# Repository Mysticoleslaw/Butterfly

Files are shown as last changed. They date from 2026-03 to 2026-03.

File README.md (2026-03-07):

# RC Butterfly Flight Controller

A flight controller for an RC butterfly that uses an ESP32 to control two wing servos based on FrSky S.bus input from a 4XR receiver.

## Features

- **Throttle Control**: Controls the flap rate (speed) of the wings
- **Aileron Control**: Controls turning by reducing flap amplitude on one wing
- **Flap Enable Switch**: On/off control for flapping
- **Opposite Wing Motion**: Wings flap in opposite directions for realistic butterfly flight
- **Failsafe Protection**: Automatically returns to neutral position if signal is lost
- **No Inverter Needed**: ESP32 handles inverted S.bus signals in hardware

## Hardware Requirements

### Required Components
- **Waveshare ESP32-C3 Mini Development Board**
- **FrSky 4XR 3/16 channel receiver** with S.bus output
- **Two standard servos** (9g or similar) for wing control
- Power supply for servos (if not powered through ESP32-C3)

### Optional Components
- USB cable for programming and debugging
- Breadboard and jumper wires for prototyping

## Wiring

```
FrSky 4XR Receiver
    |
    | S.bus OUT (direct connection, no inverter!)
    |
ESP32-C3 Mini GPIO 4 (UART1 RX)
    |
    | Control signals
    |
Servo 1 (Left Wing)  -> GPIO 5
Servo 2 (Right Wing) -> GPIO 6
```

### Pin Connections (Waveshare ESP32-C3 Mini)

| Component | ESP32-C3 Pin | Notes |
|---|---|---|
| S.bus Signal | GPIO 4 | UART1 RX |
| Left Wing Servo | GPIO 5 | PWM pin |
| Right Wing Servo | GPIO 6 | PWM pin |

**Note**: Pins are configurable. You can change `SBUS_RX_PIN`, `SERVO_LEFT_PIN`, and `SERVO_RIGHT_PIN` in the code to use different GPIO pins if needed.

## Software Setup

### 1. Install Required Libraries

1. **FrSky S.bus Library**: 
   - Copy the `frsky-sbus-main/src` folder to your Arduino `libraries` folder
   - Rename it to `FrskySbus`
   - Location: `~/Documents/Arduino/libraries/FrskySbus/`

2. **ESP32Servo Library**:
   - Install via Arduino Library Manager: Sketch → Include Library → Manage Libraries → Search "ESP32Servo"
   - Or via command line: `arduino-cli lib install "ESP32Servo"`

### 2. Install ESP32 Board Support

1. In Arduino IDE: File → Preferences → Additional Board Manager URLs
2. Add: `https://raw.githubusercontent.com/espressif/arduino-esp32/gh-pages/package_esp32_index.json`
3. Tools → Board → Boards Manager → Search "ESP32" → Install "esp32 by Espressif Systems"

### 3. Upload the Code

1. Open `ButterflyFlightController_ESP32.ino` in Arduino IDE
2. Select your board: Tools → Board → ESP32 Arduino → ESP32C3 Dev Module
3. Select the correct port: Tools → Port → [Your ESP32-C3 port]
4. Upload the sketch

## How It Works

### Flap Rate Control (Throttle)
- **Low Throttle**: Slow, gentle flapping (500ms period)
- **High Throttle**: Fast, aggressive flapping (50ms period)
- The throttle stick position directly controls the speed of wing movement

### Turning Control (Aileron)
- **Neutral**: Both wings flap with full amplitude (45° range: 45° to 135°)
- **Left Stick**: Left wing amplitude reduces (e.g., 68° to 112°), right wing keeps full amplitude → turns left
- **Right Stick**: Right wing amplitude reduces, left wing keeps full amplitude → turns right
- The differential amplitude creates asymmetric lift for turning

### Flap Enable (Channel 3)
- **ON** (above center): Flapping enabled, responds to throttle and aileron
- **OFF** (below center): Flapping disabled, wings return to center (90°), ignores throttle and aileron

### Wing Motion
- Wings flap in **opposite directions** (left up = right down, and vice versa)
- This creates realistic butterfly flapping motion
- Both wings always flap around center (90°), but with different amplitudes when turning

### Failsafe Protection
- If no S.bus signal is received for 500ms, failsafe activates
- Wings automatically return to center position
- Flapping stops
- Normal operation resumes when signal is restored

## Calibration and Tuning

### Adjusting Flap Speed Range
Modify these constants in the code:
```cpp
const unsigned long MIN_FLAP_PERIOD = 50;   // Fastest flapping (ms)
const unsigned long MAX_FLAP_PERIOD = 500;  // Slowest flapping (ms)
```

### Adjusting Flap Amplitude
Change the wing movement range:
```cpp
const int FLAP_AMPLITUDE_FULL = 45;  // Full amplitude when straight (degrees)
const int FLAP_AMPLITUDE_MIN = 22;  // Minimum amplitude when turning (degrees)
```

### Adjusting Turn Sensitivity
Modify the maximum turn reduction:
```cpp
const int MAX_TURN_REDUCTION = 23;  // Maximum amplitude reduction for turning (degrees)
```

### Adjusting Servo Range
If your servos need different limits:
```cpp
const int SERVO_MIN = 45;   // Minimum servo position (degrees)
const int SERVO_MAX = 135;  // Maximum servo position (degrees)
const int SERVO_CENTER = 90; // Center position (degrees)
```

### Channel Mapping
If your transmitter channels are different, modify:
```cpp
#define THROTTLE_CHANNEL 0  // Change to your throttle channel (0-15)
#define AILERON_CHANNEL 1   // Change to your aileron channel (0-15)
#define FLAP_ENABLE_CHANNEL 2  // Change to your enable channel (0-15)
```

## Transmitter Setup

Configure your transmitter with:
- **Channel 1**: Throttle stick (controls flap rate)
- **Channel 2**: Aileron stick (controls turning)
- **Channel 3**: 2-position or 3-position switch (enables/disables flapping)

## Troubleshooting

### No Wing Movement
1. Check that servos are connected to GPIO 18 and 19
2. Verify servo power supply (servos may need external power)
3. Check Serial Monitor for error messages
4. Verify S.bus signal is being received (check debug output)

### Erratic Movement
1. Ensure S.bus signal is reaching the ESP32
2. Check GPIO 16 connection
3. Verify transmitter is bound to receiver
4. Check that channel mapping matches your transmitter

### Failsafe Always Active
1. Verify S.bus signal is reaching GPIO 16
2. Check receiver is powered and bound
3. Ensure S.bus is enabled on receiver (some receivers need configuration)
4. Check Serial Monitor for connection status

### Wings Not Centered
1. Adjust `SERVO_CENTER` value if needed
2. Physically adjust servo horns if needed
3. Use transmitter trim if available

## Debugging

The code includes Serial output for debugging. Open Serial Monitor at 115200 baud to see:
- Throttle, aileron, and flap enable channel values
- Current flap period
- Wing amplitudes for each side
- Failsafe status

To disable debug output for production, comment out or remove the Serial.print statements in the loop.

## Why ESP32-C3 Mini?

The Waveshare ESP32-C3 Mini is ideal for this project because:
- **Hardware UART**: Dedicated hardware serial (not software emulation)
- **Native Inverted Signal Support**: Handles inverted S.bus signals in hardware - no inverter circuit needed!
- **Reliable at 100000 Baud**: Handles S.bus speed easily without jitter
- **Better Performance**: Smooth, responsive control
- **Compact Size**: Small form factor perfect for RC applications
- **Low Power**: Efficient operation for battery-powered projects

## Safety Notes

- Always test with the butterfly secured before free flight
- Start with low throttle settings to verify control
- Ensure failsafe is working before flight
- Check all connections before powering on
- Use appropriate power supply for servos (may need external supply)
- Verify all controls respond correctly before first flight

## License

This project uses the FrSky S.bus library which is based on work by Brian R Taylor and maintained by COPPERPUNK.

## Credits

- FrSky S.bus Library: [COPPERPUNK](https://github.com/copperpunk-arduino/frsky-sbus)
- Original SBUS.h library: [Brian R Taylor](https://github.com/bolderflight/SBUS)
- ESP32Servo Library: [Kevin Harrington, John K. Bennett](https://github.com/madhephaestus/ESP32Servo)

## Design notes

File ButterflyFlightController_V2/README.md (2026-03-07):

# Butterfly Flight Controller V2

Flight controller for an RC ornithopter (mechanical butterfly) running on an ESP32-C3 Mini with a FrSky RXS-R receiver.

Based on the [Ctorque Mech-Butterfly](https://github.com/) MicroPython code, rewritten in Arduino C++ with FrSky F.Port support and additional features.

## Features

- **Sinusoidal flap motion** — Smooth cosine-wave wing movement (40 steps/cycle), replacing the original binary snap flap. Produces natural, efficient wing motion.
- **Variable amplitude** — Adjust wing sweep angle in flight (20-70 degrees) via a stick or knob.
- **Pitch control** — Shift both wing centers for climb/dive bias.
- **Differential turning** — Aileron input makes one wing flap more than the other for yaw control.
- **Per-wing trim** — Independent trim correction for left and right wings via aux channels.
- **Battery monitoring** — ADC-based voltage reading with low-pass filter. Displays on serial and sends telemetry to transmitter.
- **F.Port telemetry** — Battery voltage (VFAS) and percentage (Fuel) code included but currently disabled (F.Port set to RX-only due to GPIO 7 half-duplex conflict on ESP32-C3).
- **Non-blocking** — F.Port is read every loop iteration; wing motion never blocks communication.
- **WS2812 wing LEDs** — Addressable LED effects synced to flight state: rainbow wave during flapping, amber breathing when idle, red flash on failsafe, orange pulse on low battery.
- **Failsafe** — Wings center and stop flapping if F.Port signal is lost for 500ms.

## Hardware

| Component | Details |
|---|---|
| MCU | ESP32-C3 Mini Development Board (3.3V logic) |
| Receiver | FrSky RXS-R (uninverted S.Port / F.Port on P pad) |
| Servos | 2x micro servos for wing control |
| Battery | 2S LiPo (7.4V nominal) |
| BEC | 5V BEC from 2S battery to power the ESP32-C3 via VIN pin |
| Voltage divider | Resistor divider on battery line for ADC monitoring |
| LEDs | WS2812 / NeoPixel strip (mounted on wings) |

## Wiring

```
FrSky RXS-R P pad ──── GPIO 7   (F.Port, RX only)
Left wing servo ─────── GPIO 4
Right wing servo ────── GPIO 5
Battery voltage divider  GPIO 0   (ADC input)
WS2812 LED data ──────── GPIO 3   (NeoPixel strip)
5V BEC output ────────── VIN      (ESP32-C3 power)
GND ──────────────────── GND
```

### Battery Voltage Divider

The ESP32-C3 ADC can only read up to ~2.5V (with 11dB attenuation). A resistor divider scales the battery voltage down to a safe range.

```
VBAT ──[ R1 30k ]──┬──[ R2 10k ]── GND
                   └── GPIO 0
```

With R1=30k and R2=10k, the divider ratio is 4:1.

- 2S full (8.4V) / 4 = 2.1V (safe for ADC)
- 2S empty (6.6V) / 4 = 1.65V

Set `VDIV_RATIO` in the code to match your actual resistor values:

```
VDIV_RATIO = (R1 + R2) / R2
```

**Important:** Do NOT connect the battery directly to any GPIO pin. The ESP32-C3 is a 3.3V chip — voltages above 3.3V on any GPIO will damage it.

## Channel Mapping

Configure these on your FrSky transmitter (OpenTX / EdgeTX):

| Channel | Input | Function | Range |
|---|---|---|---|
| Ch 0 | Throttle | Flap speed | Slow ↔ Fast (8-16ms/step) |
| Ch 1 | Aileron | Turning (differential) | Left ↔ Right (±20 deg) |
| Ch 2 | Elevator | Pitch offset | Dive ↔ Climb (±20 deg) |
| Ch 3 | Rudder | Flap amplitude | Small ↔ Large (20-70 deg) |
| Ch 4 | Aux switch | Flap enable/disable | Below center=off, above=on |
| Ch 5 | Aux knob/slider | Left wing trim | ±20 deg |
| Ch 6 | Aux knob/slider | Right wing trim | ±20 deg |
| Ch 7 | Aux switch | LED on/off | Below center=off, above=on |
| Ch 8 | 3-pos switch | LED mode | Low=solid, Mid=rainbow, High=flap-sync |
| Ch 9 | Aux pot/slider | LED brightness | 0-100% |
| Ch 10 | Aux pot/slider | LED color hue | Full color wheel |

## Telemetry

The controller sends battery data back through F.Port. These values appear automatically on your transmitter once discovered:

| Sensor | Value | Description |
|---|---|---|
| VFAS | Voltage | Battery voltage (e.g. 7.85V) |
| Fuel | Percentage | Battery level (0-100%) |

You can set up voice alerts on the transmitter for low battery warnings.

## LED Effects

WS2812 LEDs on GPIO 3, fully controlled from the transmitter via Ch 7-10.

**Ch 7** turns LEDs on or off. **Ch 9** controls brightness. **Ch 10** selects the color hue (used by solid and flap-sync modes).

**Ch 8** selects the mode with a 3-position switch:

| Switch position | Mode | Description |
|---|---|---|
| Low | Solid | All LEDs set to the color selected by the hue pot (Ch 10) |
| Center | Rainbow | Classic auto-cycling rainbow spread across the strip |
| High | Flap-sync | Two complementary colors alternate across the strip, swapping brightness with each wing stroke |

### Flap-sync mode

The color pot (Ch 10) picks a base hue. The complementary color (180 degrees opposite on the color wheel) is calculated automatically. Even-numbered LEDs show color A, odd-numbered show color B. As the wings flap, the two colors swap dominance — at one wing extreme color A is bright and B is dim, at the other extreme they swap. This creates a shimmering, pulsing dual-color effect synced to wing motion.

### Wiring

Power the LED strip from the **5V BEC**, not from the ESP32-C3's 3.3V pin. Connect the data line to GPIO 3 (3.3V logic is fine for WS2812 data at short wire distances).

## Tuning

All parameters are defined as constants at the top of the `.ino` file:

| Constant | Default | Description |
|---|---|---|
| `DELAY_MIN_MS` | 8 | Fastest step delay (ms) — full throttle |
| `DELAY_MAX_MS` | 16 | Slowest step delay (ms) — zero throttle |
| `AMP_MIN` | 20.0 | Minimum amplitude (degrees) |
| `AMP_MAX` | 70.0 | Maximum amplitude (degrees) |
| `DIFF_MAX` | 20.0 | Maximum turning differential (degrees) |
| `PITCH_MAX` | 20.0 | Maximum pitch offset (degrees) |
| `TRIM_MAX` | 20.0 | Maximum per-wing trim (degrees) |
| `FLAP_STEPS` | 40 | Steps per full flap cycle (smoothness) |
| `VDIV_RATIO` | 4.0 | Battery voltage divider ratio |
| `BAT_VOLT_MIN` | 6.6 | 2S LiPo empty voltage |
| `BAT_VOLT_MAX` | 8.4 | 2S LiPo full voltage |
| `BAT_WARN_VOLTAGE` | 7.0 | Low battery warning threshold |
| `BAT_FILTER_ALPHA` | 0.98 | ADC smoothing (higher = smoother) |
| `LED_COUNT` | 10 | Number of WS2812 LEDs on the strip |
| `LED_UPDATE_INTERVAL_MS` | 25 | LED refresh rate (~40fps) |
| `RAINBOW_SPEED` | 300.0 | Rainbow mode rotation speed |

## Dependencies

- [ESP32Servo](https://github.com/madhephaestus/ESP32Servo) — Install via Arduino Library Manager
- [Adafruit NeoPixel](https://github.com/adafruit/Adafruit_NeoPixel) — Install via Arduino Library Manager

## Flashing

1. Open `ButterflyFlightController_V2.ino` in Arduino IDE
2. Select board: **ESP32C3 Dev Module**
3. Set **USB CDC On Boot: Enabled** (required for serial monitor over USB)
4. Install libraries: **ESP32Servo** and **Adafruit NeoPixel**
5. Connect the ESP32-C3 via USB
6. Upload

Or via `arduino-cli`:

```bash
arduino-cli compile --fqbn esp32:esp32:esp32c3:CDCOnBoot=cdc ButterflyFlightController_V2
arduino-cli upload --fqbn esp32:esp32:esp32c3:CDCOnBoot=cdc --port /dev/cu.usbmodem1101 ButterflyFlightController_V2
```

## Known Issues

- **Servo amplitude drops at high flap speeds** — The sinusoidal wave commands positions faster than budget analog servos (e.g. ES08AII at ~0.10s/60°) can physically reach. At max throttle (320ms/cycle), servos can't complete the full sweep before the wave reverses. Fix: use faster digital servos (~0.05-0.06s/60°) like the KST X08 Plus, or increase `DELAY_MIN_MS` to cap speed to what your servos can handle.
- **Telemetry disabled** — Half-duplex F.Port on GPIO 7 caused signal loss due to the open-drain configuration interfering with RX. Telemetry code remains in the sketch but the UART is set to RX-only. May work on a different GPIO or with a separate TX pin.

## Changes from V1

| Feature | V1 | V2 |
|---|----|----|
| Flap motion | Binary snap (2 positions) | Sinusoidal cosine wave (40 steps) |
| Amplitude | Fixed 45 deg | Variable 20-70 deg (Ch 3) |
| Pitch control | None | ±20 deg (Ch 2) |
| Wing trims | None | ±20 deg per wing (Ch 5-6) |
| Battery monitoring | None | ADC with low-pass filter |
| Telemetry | None | VFAS + Fuel via F.Port |
| F.Port direction | RX only | RX only (half-duplex telemetry code present but disabled) |
| Flap speed control | Period 50-500ms | Step delay 8-16ms (smoother) |
| Wing LEDs | None | WS2812 with 3 modes, RC-controlled brightness/color/on-off |

## Credits

- Original Ctorque Mech-Butterfly MicroPython code
- Wing motion algorithm ported from `Kang_Flyer_Ornithopter.py`
- Battery monitoring approach from `Kang_Battery.py`

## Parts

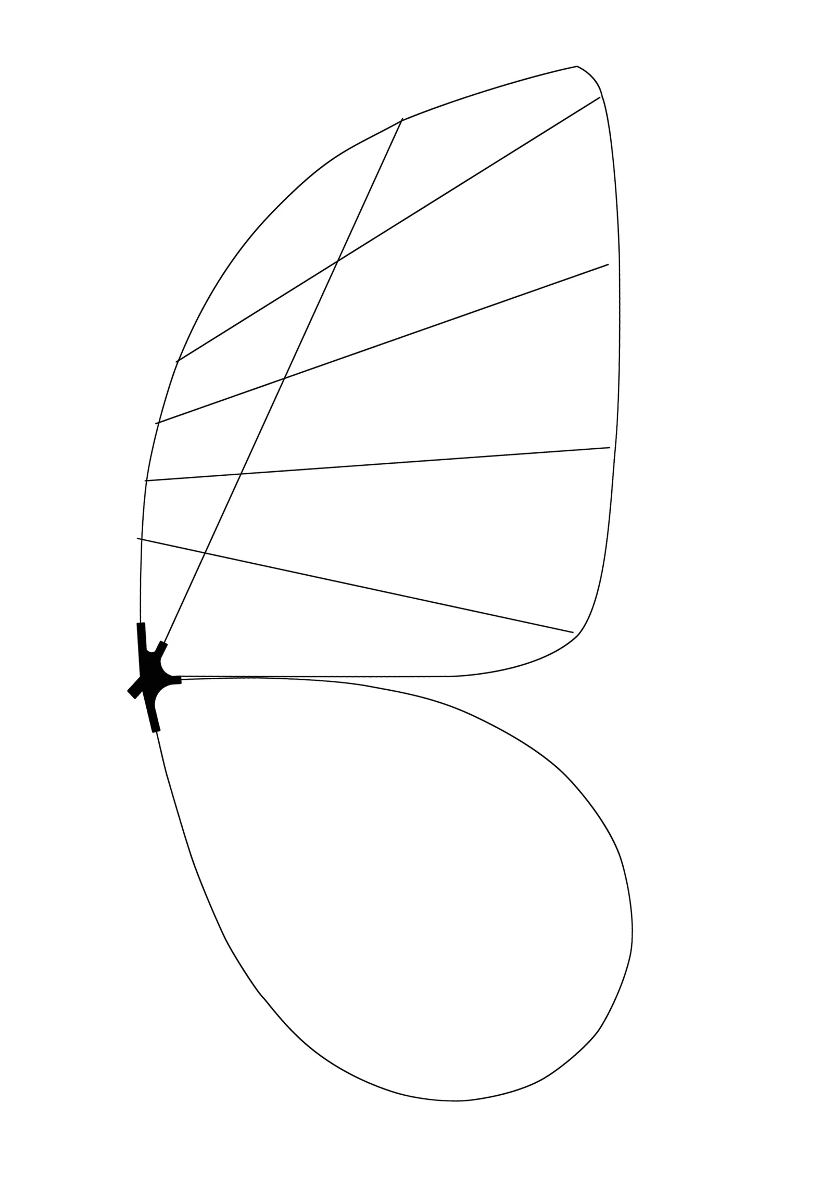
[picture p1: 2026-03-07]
Ctorque parts/a2-2-scaled.webp

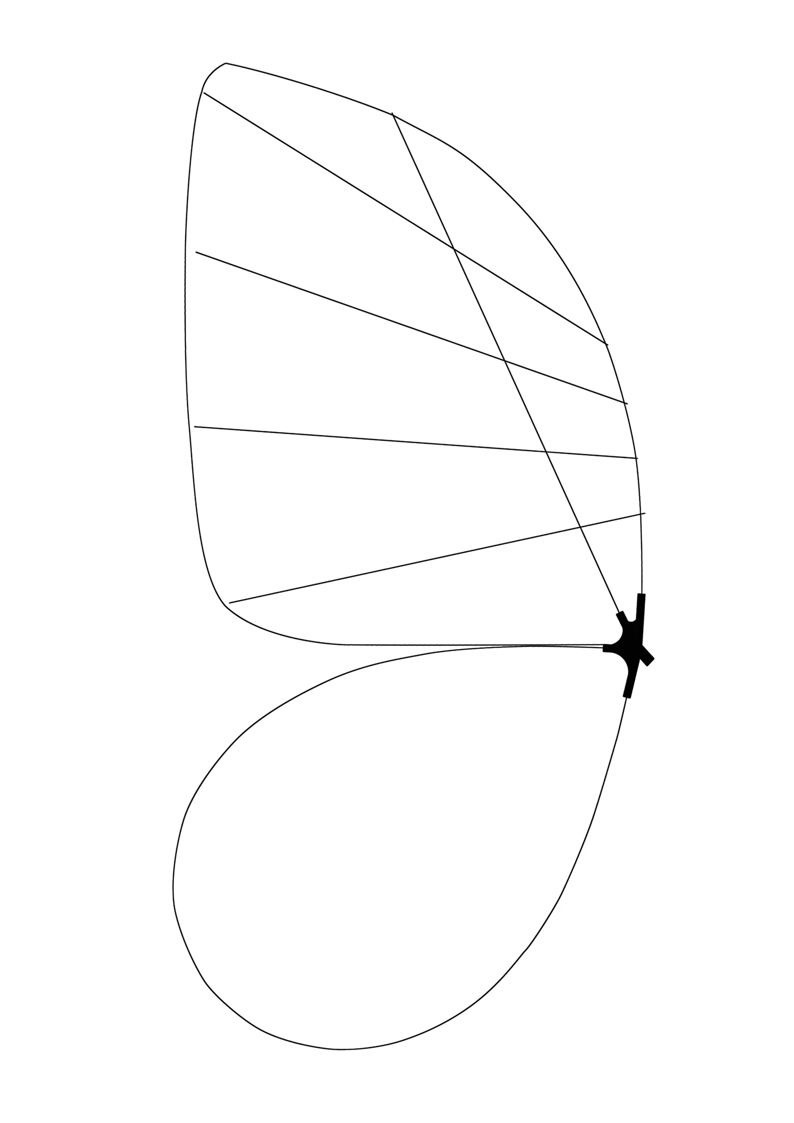
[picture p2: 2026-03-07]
Ctorque parts/A2-1-scaled.webp

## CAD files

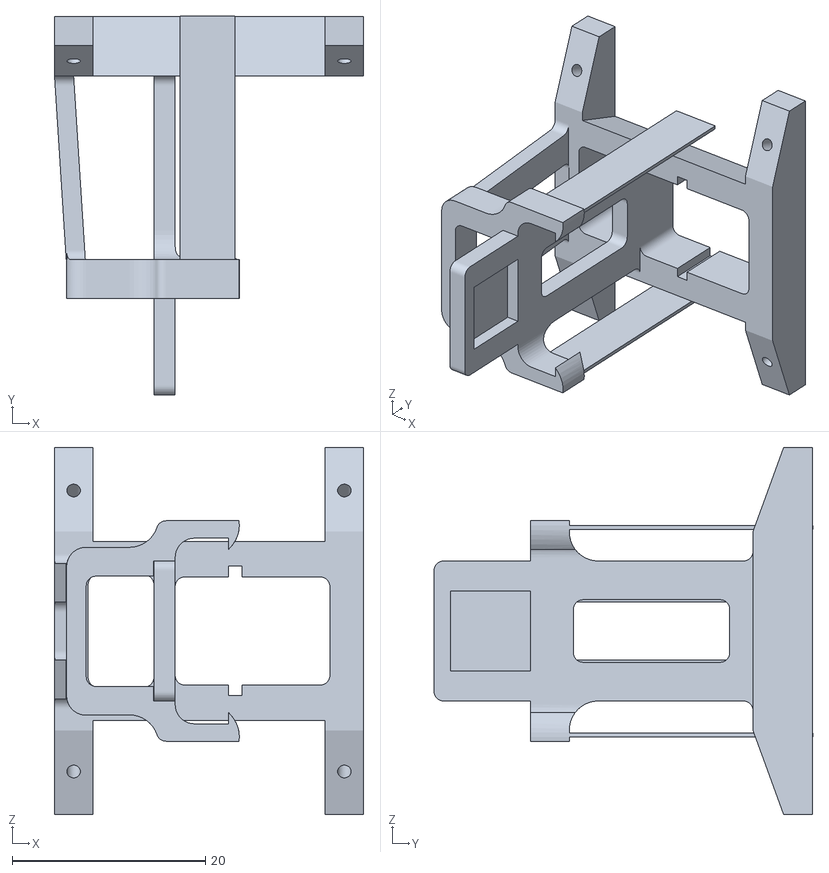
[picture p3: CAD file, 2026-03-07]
Ctorque parts/bionic butterfly mount 20260113/FC Mount V5.STL
32.0 x 39.2 x 38.0

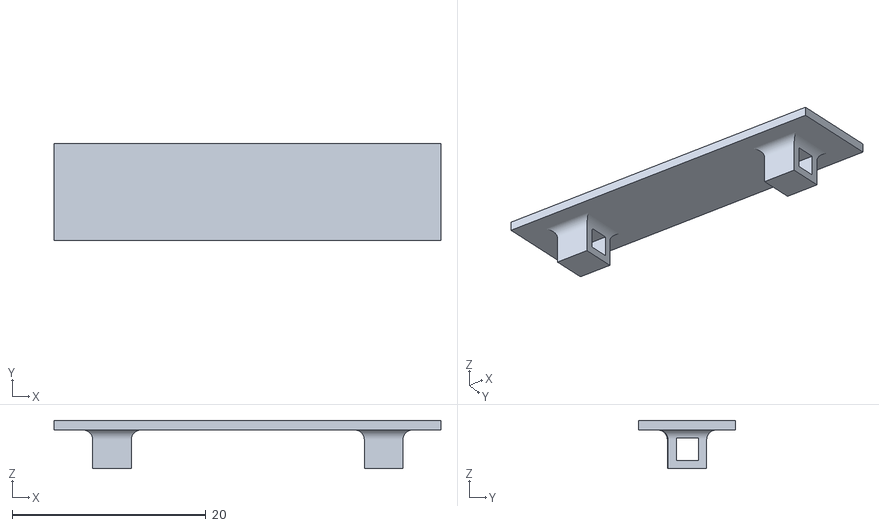
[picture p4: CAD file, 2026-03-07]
Ctorque parts/Mech-Butterfly-main/5-3D-Printed-Parts/Battery-Mount/Flight-Controller-Battery-Mount.STL
40.0 x 10.0 x 5.00

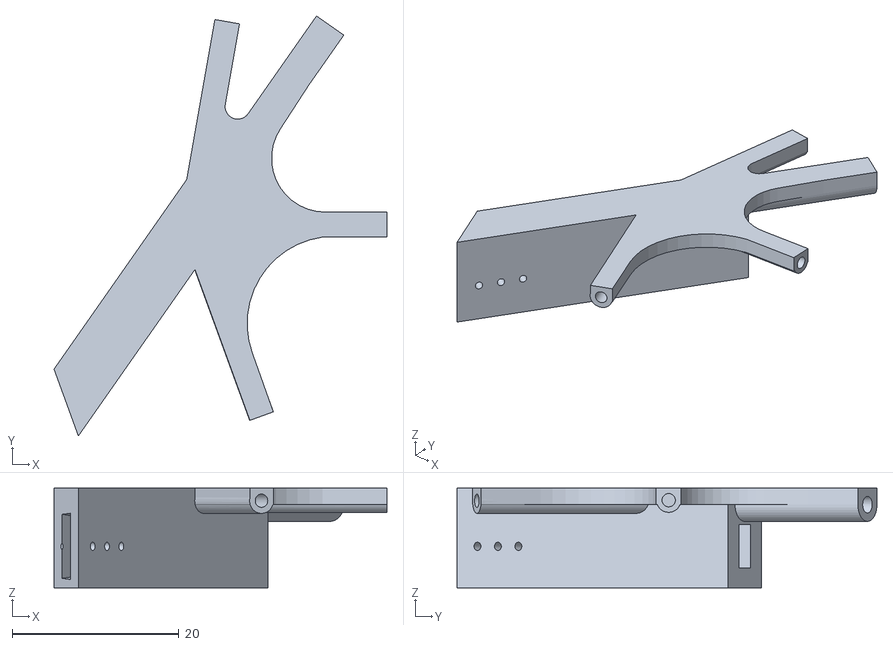
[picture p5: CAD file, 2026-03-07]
Ctorque parts/Mech-Butterfly-main/5-3D-Printed-Parts/Servo-Arm-Wing-Connector/1906B/1906 left.STL
40.0 x 50.4 x 12.0

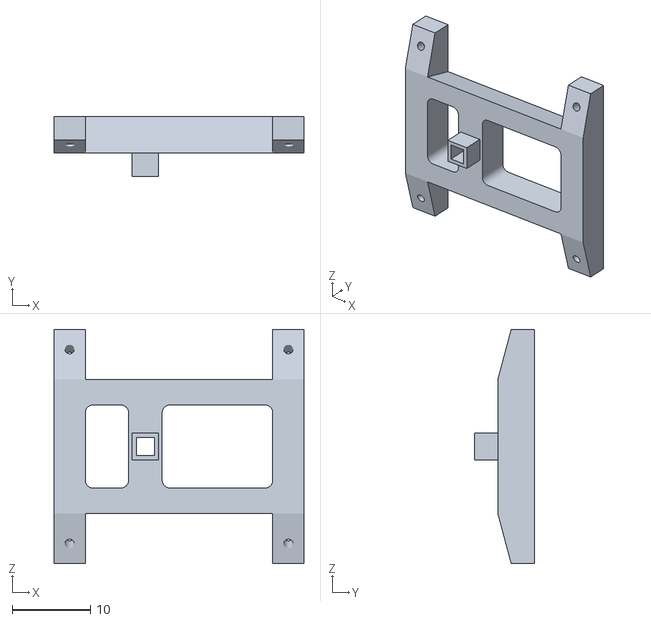
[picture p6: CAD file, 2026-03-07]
Ctorque parts/Mech-Butterfly-main/5-3D-Printed-Parts/Servo-Mount/1906B/1906-base-150.STL
32.0 x 7.72 x 30.0

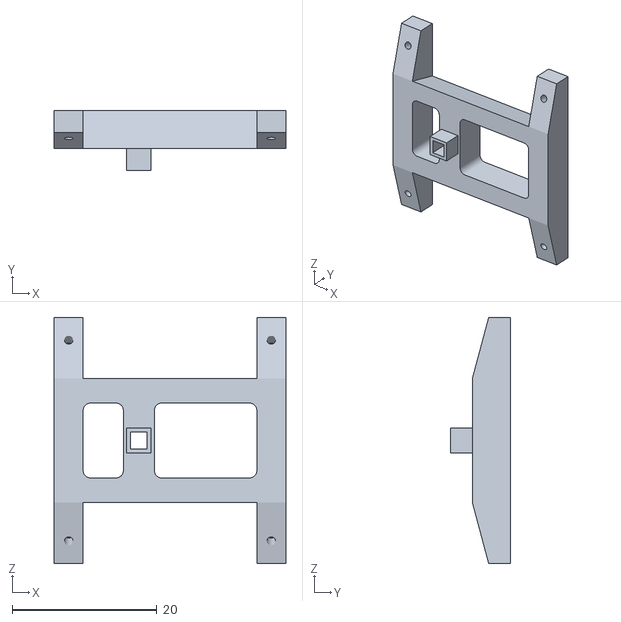
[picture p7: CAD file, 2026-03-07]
Ctorque parts/Mech-Butterfly-main/5-3D-Printed-Parts/Servo-Mount/7465/base-150.STL
32.0 x 8.26 x 34.0

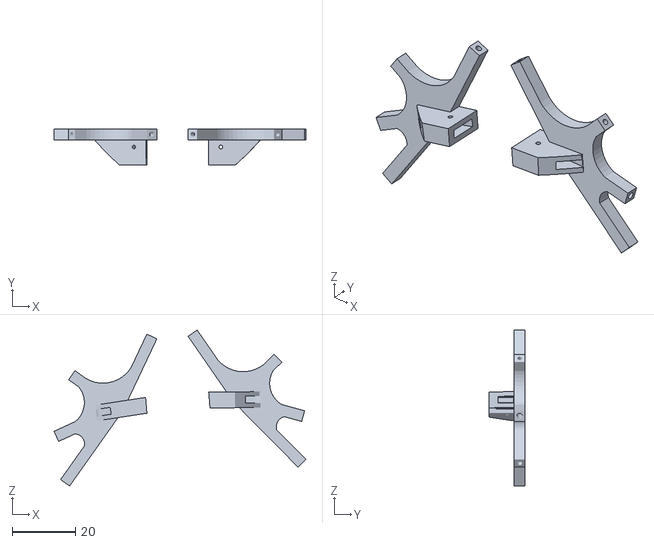
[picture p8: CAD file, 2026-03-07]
Ctorque parts/bionic butterfly mount 20260113/ARMV5.STL
79.7 x 11.5 x 49.3

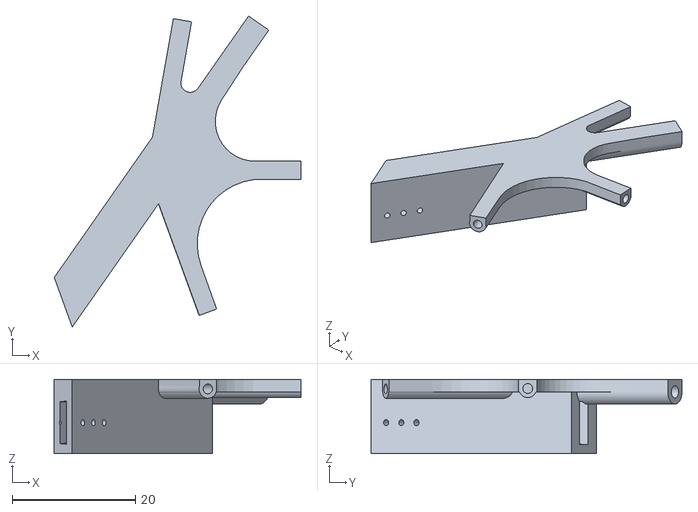
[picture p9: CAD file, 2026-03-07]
Ctorque parts/Mech-Butterfly-main/5-3D-Printed-Parts/Servo-Arm-Wing-Connector/7465/PTK left.STL
40.0 x 50.4 x 12.0

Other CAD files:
Ctorque parts/Mech-Butterfly-main/5-3D-Printed-Parts/Servo-Arm-Wing-Connector/7465/PTK right.STL
Ctorque parts/Mech-Butterfly-main/5-3D-Printed-Parts/Servo-Arm-Wing-Connector/1906B/1906 right.STL

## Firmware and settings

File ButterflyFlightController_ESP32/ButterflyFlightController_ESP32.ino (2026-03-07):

/*
 * RC Butterfly Flight Controller (ESP32 Version - No Inverter Needed!)
 * 
 * This version uses ESP32's hardware UART inversion capability
 * to handle inverted S.bus signals without a hardware inverter!
 * 
 * Controls an RC butterfly with two wing servos using FrSky S.bus input
 * - Throttle channel controls flap rate (how fast wings flap)
 * - Aileron channel controls turning (differential wing movement)
 * - Flap Enable channel controls on/off (enable/disable flapping)
 * 
 * Hardware Requirements:
 * - ESP32 board
 * - FrSky 4XR receiver with S.bus output
 * - NO INVERTER NEEDED! ESP32 handles inversion in hardware
 * - Two servos for wing control
 * 
 * Wiring:
 * - S.bus output from receiver (DIRECT, no inverter!) -> GPIO 16 (UART2 RX)
 * - Servo 1 (Left wing) -> GPIO 18
 * - Servo 2 (Right wing) -> GPIO 19
 * 
 * Channel Mapping (default):
 * - Channel 1: Throttle (flap rate)
 * - Channel 2: Aileron (turning)
 * - Channel 3: Flap Enable (on/off switch)
 * 
 * NOTE: ESP32 has hardware support for inverted UART signals,
 * eliminating the need for a hardware inverter!
 */

#include "FrskySbus.h"
#include <ESP32Servo.h>

// Hardware configuration
#define SBUS_RX_PIN 16   // GPIO 16 for S.bus RX (UART2 on ESP32)
#define SERVO_LEFT_PIN 18
#define SERVO_RIGHT_PIN 19

// ESP32 HardwareSerial with inverted signal support
HardwareSerial sbusSerial(2); // Use UART2 on ESP32
FrskySbus frsky_(sbusSerial);

// Servo objects
Servo servoLeft;
Servo servoRight;

// Channel mapping (adjust based on your transmitter setup)
#define THROTTLE_CHANNEL 0  // Channel 1 (0-indexed)
#define AILERON_CHANNEL 1   // Channel 2 (0-indexed)
#define FLAP_ENABLE_CHANNEL 2  // Channel 3 (0-indexed) - on/off switch

// Control parameters
const uint16_t SBUS_MIN = 172;   // Minimum S.bus value
const uint16_t SBUS_MAX = 1811;  // Maximum S.bus value
const uint16_t SBUS_CENTER = 992; // Center S.bus value

// Flap control parameters
const unsigned long MIN_FLAP_PERIOD = 50;   // Minimum time between flaps (ms) - faster flapping
const unsigned long MAX_FLAP_PERIOD = 500;  // Maximum time between flaps (ms) - slower flapping
const int FLAP_AMPLITUDE_FULL = 45;        // Full flap amplitude (degrees) - both wings when straight
const int FLAP_AMPLITUDE_MIN = 22;         // Minimum flap amplitude when turning (degrees)
const int SERVO_CENTER = 90;               // Center position for servos (degrees)
const int SERVO_MIN = 30;                  // Minimum servo position (degrees) - increased range for turning
const int SERVO_MAX = 150;                 // Maximum servo position (degrees) - increased range for turning

// Turn control parameters
const int MAX_TURN_REDUCTION = 23;  // Maximum reduction in flap amplitude for turning (degrees)

// Wing state
int leftWingAmplitude = FLAP_AMPLITUDE_FULL;   // Current flap amplitude for left wing
int rightWingAmplitude = FLAP_AMPLITUDE_FULL;  // Current flap amplitude for right wing
int leftWingPos = SERVO_CENTER;
int rightWingPos = SERVO_CENTER;

// Flap timing
unsigned long lastFlapTime = 0;
unsigned long flapPeriod = 200;  // Default flap period (ms)
bool flapDirection = true;       // true = up, false = down
bool flappingEnabled = false;   // Enable/disable flapping based on channel 3

// Safety
bool failsafeActive = false;
bool lostFrame = false;
unsigned long lastValidFrameTime = 0;
const unsigned long FAILSAFE_TIMEOUT = 500; // ms without valid frame = failsafe

void setup() {
  // Initialize serial for debugging
  Serial.begin(115200);
  while (!Serial && millis() < 3000) {
    ; // Wait for serial port or timeout after 3 seconds
  }
  Serial.println("RC Butterfly Flight Controller (ESP32 - No Inverter!)");
  Serial.println("Initializing...");

  // Initialize ESP32 UART with inverted signal support
  // ESP32 can invert the signal in hardware - no external inverter needed!
  sbusSerial.begin(100000, SERIAL_8E2, SBUS_RX_PIN, -1, true); // baud, config, RX, TX, invert
  // Note: The 'invert' parameter (true) tells ESP32 to invert the signal in hardware
  
  // Clear buffer
  while (sbusSerial.available() > 0) {
    sbusSerial.read();
  }
  Serial.println("S.bus initialized (ESP32 hardware inversion)");
  Serial.print("S.bus RX pin: GPIO ");
  Serial.println(SBUS_RX_PIN);

  // Attach servos
  servoLeft.attach(SERVO_LEFT_PIN);
  servoRight.attach(SERVO_RIGHT_PIN);
  
  // Set servos to center position
  servoLeft.write(SERVO_CENTER);
  servoRight.write(SERVO_CENTER);
  Serial.print("Servos attached - Left: GPIO ");
  Serial.print(SERVO_LEFT_PIN);
  Serial.print(" | Right: GPIO ");
  Serial.println(SERVO_RIGHT_PIN);
  Serial.println("Servos initialized and centered at 90 degrees");

  // Initialize timing
  lastFlapTime = millis();
  lastValidFrameTime = millis();

  Serial.println("Ready!");
  Serial.println("Waiting for S.bus signal...");
}

void loop() {
  // Check for new S.bus message
  if (frsky_.checkForNewMessage()) {
    lastValidFrameTime = millis();
    failsafeActive = frsky_.isFailsafeActive();
    lostFrame = frsky_.lostFrame();

    if (!failsafeActive && !lostFrame) {
      // Read channel values
      uint16_t throttle = frsky_.getChannelValue(THROTTLE_CHANNEL);
      uint16_t aileron = frsky_.getChannelValue(AILERON_CHANNEL);
      uint16_t flapEnable = frsky_.getChannelValue(FLAP_ENABLE_CHANNEL);

      // Check if flapping is enabled (channel 3 above center = enabled)
      flappingEnabled = (flapEnable > SBUS_CENTER);

      // Only process throttle and aileron inputs if flapping is enabled
      if (flappingEnabled) {
        // Map throttle to flap rate
        // Higher throttle = faster flapping (shorter period)
        flapPeriod = map(throttle, SBUS_MIN, SBUS_MAX, MAX_FLAP_PERIOD, MIN_FLAP_PERIOD);
        flapPeriod = constrain(flapPeriod, MIN_FLAP_PERIOD, MAX_FLAP_PERIOD);

        // Map aileron to turn adjustment
        // Negative aileron (left) = reduce left wing, increase right wing by same amount
        // Positive aileron (right) = reduce right wing, increase left wing by same amount
        int aileronValue = map(aileron, SBUS_MIN, SBUS_MAX, -100, 100);  // -100 to +100
        
        // Calculate amplitude changes for each wing
        // When turning, decrease amplitude on one side and increase on the other by the SAME amount
        // This creates balanced asymmetric lift for better turning
        int amplitudeChange = map(abs(aileronValue), 0, 100, 0, MAX_TURN_REDUCTION);
        
        if (aileronValue < 0) {
          // Turning left - reduce left wing amplitude, increase right wing amplitude by same amount
          leftWingAmplitude = FLAP_AMPLITUDE_FULL - amplitudeChange;
          rightWingAmplitude = FLAP_AMPLITUDE_FULL + amplitudeChange;  // Increase by same amount
        } else if (aileronValue > 0) {
          // Turning right - reduce right wing amplitude, increase left wing amplitude by same amount
          rightWingAmplitude = FLAP_AMPLITUDE_FULL - amplitudeChange;
          leftWingAmplitude = FLAP_AMPLITUDE_FULL + amplitudeChange;  // Increase by same amount
        } else {
          // Flying straight - both wings full amplitude
          leftWingAmplitude = FLAP_AMPLITUDE_FULL;
          rightWingAmplitude = FLAP_AMPLITUDE_FULL;
        }
        
        // Constrain amplitudes to safe range
        // Allow increased amplitude up to full + MAX_TURN_REDUCTION for better turning
        int maxAmplitude = FLAP_AMPLITUDE_FULL + MAX_TURN_REDUCTION;
        leftWingAmplitude = constrain(leftWingAmplitude, FLAP_AMPLITUDE_MIN, maxAmplitude);
        rightWingAmplitude = constrain(rightWingAmplitude, FLAP_AMPLITUDE_MIN, maxAmplitude);
      } else {
        // Flapping disabled - ignore all inputs and return to neutral
        leftWingAmplitude = FLAP_AMPLITUDE_FULL;
        rightWingAmplitude = FLAP_AMPLITUDE_FULL;
        flapPeriod = MAX_FLAP_PERIOD;
      }

      // Debug output (can be disabled for production)
      static unsigned long lastDebugTime = 0;
      if (millis() - lastDebugTime > 100) {  // Print every 100ms
        Serial.print("Throttle: ");
        Serial.print(throttle);
        Serial.print(" | Aileron: ");
        Serial.print(aileron);
        Serial.print(" | Flap Enable: ");
        Serial.print(flapEnable);
        Serial.print(" | Flapping: ");
        Serial.print(flappingEnabled ? "ON" : "OFF");
        Serial.print(" | Flap Period: ");
        Serial.print(flapPeriod);
        Serial.print(" | Left Amp: ");
        Serial.print(leftWingAmplitude);
        Serial.print(" | Right Amp: ");
        Serial.println(rightWingAmplitude);
        lastDebugTime = millis();
      }
    }
  }

  // Check for failsafe timeout
  if (millis() - lastValidFrameTime > FAILSAFE_TIMEOUT) {
    failsafeActive = true;
  }

  // Handle failsafe - return wings to neutral position
  if (failsafeActive) {
    leftWingAmplitude = FLAP_AMPLITUDE_FULL;
    rightWingAmplitude = FLAP_AMPLITUDE_FULL;
    flapPeriod = MAX_FLAP_PERIOD;  // Slow down flapping
    Serial.println("FAILSAFE ACTIVE - Returning to neutral");
  }

  // Flap the wings (only if enabled)
  unsigned long currentTime = millis();
  
  if (flappingEnabled) {
    if (currentTime - lastFlapTime >= flapPeriod) {
      lastFlapTime = currentTime;
      
      // Toggle flap direction
      flapDirection = !flapDirection;
      
      // Calculate wing positions
      // Both wings flap around center (90 degrees)
      // Left wing: normal motion (up when flapDirection is true)
      // Right wing: INVERTED motion (down when flapDirection is true) for opposite flapping
      // Turning reduces amplitude on one side, creating asymmetric lift
      if (flapDirection) {
        // Left wing up, right wing down (opposite motion)
        leftWingPos = SERVO_CENTER + leftWingAmplitude;
        rightWingPos = SERVO_CENTER - rightWingAmplitude;
      } else {
        // Left wing down, right wing up (opposite motion)
        leftWingPos = SERVO_CENTER - leftWingAmplitude;
        rightWingPos = SERVO_CENTER + rightWingAmplitude;
      }
      
      // Constrain to safe servo range
      leftWingPos = constrain(leftWingPos, SERVO_MIN, SERVO_MAX);
      rightWingPos = constrain(rightWingPos, SERVO_MIN, SERVO_MAX);
      
      // Update servos
      servoLeft.write(leftWingPos);
      servoRight.write(rightWingPos);
    }
  } else {
    // Flapping disabled - return wings to center position
    servoLeft.write(SERVO_CENTER);
    servoRight.write(SERVO_CENTER);
    lastFlapTime = currentTime; // Reset timer so it starts immediately when enabled
  }
}

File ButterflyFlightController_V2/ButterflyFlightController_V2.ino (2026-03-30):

/*
 * RC Butterfly Flight Controller V2 (ESP32-C3 Mini + FrSky RXS-R)
 *
 * Smooth sinusoidal wing motion with advanced controls,
 * ported from the Ctorque MicroPython ornithopter code.
 *
 * Uses F.Port protocol from the uninverted S.Port pad on RXS-R.
 * Sends battery telemetry back to the transmitter via F.Port.
 *
 * Features:
 *   - Sinusoidal flap motion (cosine wave, 40 steps per cycle)
 *   - Variable flap amplitude via stick/knob
 *   - Pitch control (shifts wing center for climb/dive)
 *   - Per-wing trim correction via aux channels
 *   - Differential turning
 *   - Battery voltage monitoring with low-pass filter
 *   - F.Port telemetry: battery voltage + percentage on transmitter
 *   - WS2812 LED effects on wings (synced to flap motion)
 *   - Non-blocking: F.Port is read every loop, not blocked during flap
 *
 * Channel Mapping (configure on your transmitter):
 *   Ch 0  Throttle   -> Flap speed (low=slow, high=fast)
 *   Ch 1  Aileron    -> Turning (differential wing amplitude)
 *   Ch 2  Elevator   -> Pitch control (wing center offset)
 *   Ch 3  Rudder     -> (unused)
 *   Ch 4  Aux 1      -> Flap enable/disable (switch, >center = on)
 *   Ch 5  Aux 2      -> Left wing trim
 *   Ch 6  Aux 3      -> Right wing trim
 *   Ch 7  Aux 4      -> LED on/off (switch, >center = on)
 *   Ch 8  Aux 5      -> LED mode (3-pos: solid / rainbow / flap-sync)
 *   Ch 9  Aux 6      -> LED brightness (pot/slider)
 *   Ch 10 Aux 7      -> LED color hue (pot/slider)
 *
 * Telemetry (appears on transmitter automatically):
 *   VFAS  -> Battery voltage
 *   Fuel  -> Battery percentage
 *
 * Wiring:
 *   F.Port (receiver P pad) -> GPIO 8
 *   Left wing servo         -> GPIO 5
 *   Right wing servo        -> GPIO 6
 *   WS2812 LED chain        -> GPIO 3 (onboard LED is pixel 0, strip follows)
 *   Battery voltage divider  -> GPIO 0
 *   WS2812 LED data line    -> GPIO 3
 *
 * Battery circuit:
 *   VBAT ──[ R1 ]──┬──[ R2 ]── GND
 *                  └── GPIO 0
 *   Divider ratio = (R1 + R2) / R2
 *   Ctorque board uses ratio of 4 (e.g. R1=30k, R2=10k)
 *   Adjust VDIV_RATIO below to match your resistors.
 */

#include <ESP32Servo.h>
#include <Adafruit_NeoPixel.h>
#include "driver/gpio.h"

// ── Pin Configuration ───────────────────────────────────────────────
#define FPORT_RX_PIN    8
#define SERVO_LEFT_PIN  5
#define SERVO_RIGHT_PIN 6
#define BATTERY_ADC_PIN 0   // Must be ADC-capable (GPIO 0-4 on ESP32-C3)
#define LED_PIN         10  // Onboard WS2812 on GPIO 10 (Waveshare C3-Zero), chain strip from data-out
#define LED_COUNT       11  // Onboard LED + 10 strip LEDs (onboard is pixel 0)

// ── UART for F.Port (half-duplex) ──────────────────────────────────
HardwareSerial fportSerial(1);

// ── Servos ──────────────────────────────────────────────────────────
Servo servoLeft;
Servo servoRight;

// ── WS2812 LEDs ─────────────────────────────────────────────────────
Adafruit_NeoPixel strip(LED_COUNT, LED_PIN, NEO_GRB + NEO_KHZ800);

// ── Channel Mapping ─────────────────────────────────────────────────
#define CH_THROTTLE     0  // Flap speed
#define CH_AILERON      1  // Turning / differential
#define CH_ELEVATOR     2  // Pitch offset
#define CH_RUDDER       3  // Flap amplitude
#define CH_FLAP_ENABLE  4  // On/off switch
#define CH_TRIM_LEFT    5  // Left wing trim
#define CH_TRIM_RIGHT   6  // Right wing trim
#define CH_LED_ENABLE   7  // LED on/off switch
#define CH_LED_MODE     8  // LED mode (3-pos switch)
#define CH_LED_BRIGHT   9  // LED brightness (pot/slider)
#define CH_LED_COLOR    10 // LED color hue (pot/slider)

// ── F.Port Constants ────────────────────────────────────────────────
#define FPORT_HEADER     0x7E
#define FPORT_ESCAPE     0x7D
#define FPORT_ESCAPE_XOR 0x20

// Frame types
#define FPORT_TYPE_CONTROL  0x00   // RC channel data
#define FPORT_TYPE_DOWNLINK 0x01   // Telemetry poll from receiver
#define FPORT_TYPE_UPLINK   0x81   // Telemetry response from FC

// Parser result codes
#define FRAME_NONE 0
#define FRAME_RC   1
#define FRAME_POLL 2

// SmartPort sensor app IDs (show up on transmitter)
#define APPID_VFAS 0x0210  // Battery voltage (centivolts)
#define APPID_FUEL 0x0600  // Fuel level (percentage)

// Our telemetry physical ID (0x00-0x1B, receiver auto-discovers)
#define TELEM_PHYS_ID 0x00

// ── Channel Value Range (S.Bus encoding) ────────────────────────────
const uint16_t CH_MIN    = 172;
const uint16_t CH_MAX    = 1811;
const uint16_t CH_CENTER = 992;

// ── Servo Limits ────────────────────────────────────────────────────
const int SERVO_CENTER    = 90;
const int SERVO_LIMIT_MIN = 0;
const int SERVO_LIMIT_MAX = 180;

// ── Sinusoidal Flap Parameters ──────────────────────────────────────
// 40 steps per full cosine cycle (matches Ctorque: 20 up + 20 down)
const int   FLAP_STEPS      = 40;
const float PHASE_INCREMENT = TWO_PI / FLAP_STEPS;

// Step delay range (ms) — controls flap speed
// Full cycle time = FLAP_STEPS * delay = 376ms (fast) to 536ms (slow)
const int DELAY_MIN_MS = 9;   // Fastest (full throttle) — matches Ctorque V5
const int DELAY_MAX_MS = 13;  // Slowest (zero throttle) — matches Ctorque V5

// Fixed amplitude (degrees from center) — full PWM range (500-2500us) gives true 180°
const float FLAP_AMPLITUDE = 95.0;

// Differential range for turning (degrees)
const float DIFF_MAX = 20.0;

// Pitch offset range (degrees)
const float PITCH_MAX = 20.0;

// Default pitch bias (degrees) — angles wings up for baseline lift
const float PITCH_BIAS = 8.0;

// Per-wing trim range (degrees)
const float TRIM_MAX = 20.0;

// ── Battery Monitoring ──────────────────────────────────────────────
// Voltage divider ratio: (R1+R2)/R2. Ctorque board uses 4.0.
// Set this to match your resistor divider so the ADC reads within range.
const float VDIV_RATIO = 4.0;

// Battery voltage thresholds — adjust for your cell count
// 1S LiPo: min=3.3  max=4.2
// 2S LiPo: min=6.6  max=8.4
const float BAT_VOLT_MIN = 6.6;
const float BAT_VOLT_MAX = 8.4;

// Low-pass filter coefficient (0.0–1.0, higher = smoother but slower)
const float BAT_FILTER_ALPHA = 0.98;

// How often to read / print battery info (ms)
const unsigned long BAT_READ_INTERVAL_MS  = 100;
const unsigned long BAT_PRINT_INTERVAL_MS = 5000;

// Voltage at which to warn on serial
const float BAT_WARN_VOLTAGE = 7.0;

// ── WS2812 LED Settings ─────────────────────────────────────────────
// How often to update LED effects (ms) — ~40fps
const unsigned long LED_UPDATE_INTERVAL_MS = 25;

// LED modes (selected by 3-position switch on CH_LED_MODE)
#define LED_MODE_SOLID     0
#define LED_MODE_RAINBOW   1
#define LED_MODE_FLAPSYNC  2

// Rainbow cycle speed (higher = faster rotation)
const float RAINBOW_SPEED = 300.0;

// ── Failsafe ────────────────────────────────────────────────────────
const unsigned long FAILSAFE_TIMEOUT_MS = 500;
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

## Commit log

2026-03-07 feat: add ButterflyFlightController V2 with sinusoidal flap motion
    V2 changes from ESP32C3_RXSR version:
    - Sinusoidal wing motion (cosine wave, 40 steps/cycle) replacing bang-bang
    - Variable flap amplitude via Ch3 (Rudder)
    - Pitch control via Ch2 (Elevator) for climb/dive
    - Per-wing trim via Ch5/Ch6 (Aux 2/3)
    - Differential turning via Ch1 (Aileron)
    - Battery voltage monitoring with low-pass filter
    - WS2812 LED effects (solid/rainbow/flap-sync) on Ch7-Ch10
    - F.Port telemetry code (VFAS + Fuel) - currently disabled
    Post-upload fixes:
    - Switched F.Port UART to RX-only (TX disabled) to fix receiver
    signal loss caused by half-duplex open-drain config on GPIO 7
    - Disabled telemetry poll handle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
    [1906 left.STL, 1906 right.STL, 1906-base-150.STL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]
2026-03-07 docs: update V2 README to reflect current state
    - F.Port listed as RX-only (telemetry disabled)
    - Added USB CDC On Boot requirement for serial monitor
    - Added arduino-cli flash commands
    - Added Known Issues section (servo speed, telemetry)
2026-03-30 feat: tune V2 flight controller for Waveshare C3-Zero with PTK 7465 servos
    - Remap pins: F.Port to GPIO 8, servos to GPIO 5/6, LEDs to GPIO 10
    - Fix servo PWM range to 500-2500us for full 180° travel (matching Ctorque)
    - Lock flap amplitude at 95° and remove rudder channel control
    - Add +8° pitch bias for baseline lift generation
    - Match Ctorque V5 flap timing: 40 steps, 9-13ms delay per step
    - Add onboard WS2812 LED as pixel 0 in strip chain on GPIO 10
    - Add RGB blink test on boot and debug serial output
    [ButterflyFlightController_V2.ino]
